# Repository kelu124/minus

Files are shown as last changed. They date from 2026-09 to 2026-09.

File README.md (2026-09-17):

# minus

**A minimal, single-channel, low-cost, open-source ultrasound pulse-echo platform —
built as a conference-workshop badge.**

`minus` drives one piezo transducer with a high-voltage pulse, amplifies and digitizes
the returning echo, and streams the raw data to a host. It is designed to be **cheap,
small, simple, and hackable** — a badge attendees can use in an ultrasound-conference
workshop (e.g. **muscle-contraction monitoring**, A-/M-mode) and then extend and
experiment with (coded excitation, on-device DSP, add-on boards).

> ⚠️ **Status: early design.** This repository currently holds the **requirements,
> a survey of comparable systems, a component trade study, and reference designs** —
> not yet a finished board. Non-clinical, for **research / education / NDT** only;
> not a medical device.

## What it is (at a glance)

- **MCU:** Raspberry Pi **RP2350** — precise pulse timing + fast ADC capture via PIO.
- **Signal:** **3–4 MHz** piezo (provided with the kit), **raw RF** A-mode + M-mode.
- **Front end:** unipolar HV pulser (bipolar option) → T/R switch → VGA/TGC → external
  high-speed ADC. Reuses proven blocks from the author's open boards.
- **Badge:** on-board **USB-C** (host + power), **RGB LED + small OLED** for standalone
  display, **Raspberry-Pi 40-pin** extension header, transducer via **SMA / header / uFL**,
  friendly silkscreen + test points, OSHWA certification planned.
- **Open:** open hardware + firmware + host software; designed for JLCPCB fabrication.

## Repository map

| Path | What's there |
|---|---|
| [`requirements.md`](requirements.md) | The design requirements (MoSCoW), with open decisions. |
| [`analysis.md`](analysis.md) | Architecture analysis — integrated vs external-ADC routes; pulser and gain options. |
| [`options.md`](options.md) + [`options_prices.csv`](options_prices.csv) | Component trade study (pulser / gain / ADC) with LCSC-referenced pricing. |
| [`systems/`](systems/README.md) | Survey of ~19 comparable ultrasound systems (datasheets, literature, by-IC index). |
| [`design/`](design/README.md) | Reference design files (un0rick, lit3rick, pic0rick, Open Echo, BioGAP shield). |
| [`pdfs/`](pdfs/README.md) | Source papers and component datasheets. |
| [`docs/claude/`](docs/claude/README.md) | Working notes: session logs, decision memory, TODO/DONE, changelog. |

## Lineage & credits

`minus` builds on the open single-channel ultrasound work of **Luc Jonveaux (kelu124)** —
[echomods/Murgen](https://github.com/kelu124/echomods),
[un0rick](https://github.com/kelu124/un0rick),
[lit3rick](https://github.com/kelu124/lit3rick), and
[pic0rick](https://github.com/kelu124/pic0rick) — reusing their proven building blocks
to reduce risk. See [`systems/`](systems/README.md) for the broader field survey.

## License

Intended to be released as **open hardware + open software** (OSHWA certification
planned), following the licensing of the boards above.

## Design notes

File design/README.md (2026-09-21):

# design — schematics & design files

Schematics, PCB / layout, Gerbers, BOMs, and other design source files for
reference designs (and, later, for *minus* itself). **One subfolder per design**,
named to match the system slug in [`../systems/`](../systems/) where one exists.

Convention:
- `design/<name>/` — e.g. `design/un0rick/`, `design/pic0rick/`, `design/iup/`.
- Put the raw design files here (KiCad, Gerbers, PDF schematics, BOM CSVs).
- Cross-link from the matching `systems/<name>/<name>.md` datasheet.
- Large binaries are fine, but prefer the canonical/original files; note the
  upstream source (repo URL + commit/version) in a short `SOURCE.md` per subfolder.

Datasheets and papers (not editable design files) go in
[`../pdfs/`](../pdfs/) instead.

## Collected so far

| Subfolder | Design | Contents |
|---|---|---|
| `un0rick/` | un0rick (iCE40 single-channel) | schematic PDF, BOM, gerbers, drills |
| `lit3rick/` | lit3rick (UP5K single-channel) | schematics PDF, BOM, gerbers, drills |
| `pic0rick/` | pic0rick (RP2040) — 3 boards | KiCad + schematic PDFs + gerbers for `adc/`, `mux/`, `panel_adc_pulser_hv/` |
| `biogap-wulpus-pro/` | BioGAP WULPUS-pro shield (MSP430FR5043) | schematics PDF, assembly PDF, BOM (Altium source upstream) |
| `open-echo/` | Open Echo TUSS4470 shield | KiCad sch/pcb/pro + gerbers + BOM |
| `pic32/` | **Concept** (no design files yet) | Thoughts on pairing a Microchip PIC32A (PIC32AK…GC41064: 40 Msps ADC + 100 MHz op-amps) with the RP2350 as an alternative acquisition architecture. |
| `designA/` | **Concept spec** (no design files yet) | Cheapest *minus* build: RP2354A + PIC32A, 5 V push-pull pulser, digipot-set gain; active-IC BOM ≈ $4.7 / board ≈ $6. |
| `devkit/` | **Concept spec** (no design files yet) | DesignA-DK: large, fully broken-out RP2354A + PIC32AK **derisking board** — one board, jumper-selected RX front-ends (FE-0…FE-D), gain-control options, pulser bench, SMA taps. |

Each has a `SOURCE.md` with the upstream repo URL + commit + retrieval date.
More to come (IUP if released, and the leads in `docs/claude/TODO.md`).

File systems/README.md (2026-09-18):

# systems — lightweight ultrasound acquisition survey

A survey of "lightweight" / low-cost single- and few-channel ultrasound
acquisition designs, used as background for **minus**. Sources: the
[wulrick extended platform survey](https://github.com/kelu124/wulrick#othersystems-extended-platform-survey)
and its `OtherSystems/` files, each system's primary papers/repos, and online
datasheets. **Scope:** single- to few-channel designs; **64+ element systems are
out of scope** (listed at the bottom for context only).

- **[`TEMPLATE.md`](TEMPLATE.md)** — the datasheet template. Copy into a new
  subfolder as `<slug>/<slug>.md` and fill it in. Covers MCU/FPGA, pulser
  (polarity/voltage), acquisition route, ADC, gain/TGC, connectivity bandwidth,
  wireless, channel scheme, performance, and power.
- **[`literature.md`](literature.md)** — broad literature review (≤32-element
  designs) distilled from the Jonveaux et al. 2022 open-hardware survey, plus
  component menus (pulsers, HV, TGC, ADC, AFE) and single-element B-mode strategies.
- **[`by-ic.md`](by-ic.md)** — designs grouped by key IC (MSP430FR5043, TUSS4470,
  AD833x, MD1213/TC6320, …) so a part choice traces to working references.
- **[`afe-vga-ics.md`](afe-vga-ics.md)** — survey of RX gain ICs (LNA + variable-gain /
  AFE), single-channel through 8/16-channel, for the *minus* gain stage.
- One subfolder per design/product. Source/confidence tags in each sheet:
  `[D]` datasheet/repo · `[P]` paper · `[S]` slides/survey · `[E]` estimate · `?` unknown.
- Source PDFs live in [`../pdfs/`](../pdfs/) (see its README).

## Systems at a glance

| System | Year | Arch | Channels | Pulser | ADC | Gain/TGC | Link | Power | Sheet |
|---|---|---|---|---|-----|---|---|---|---|
| **Murgen** (echOpen) | 2016 | MCU + modules | 1 | HV module | external | VGA (TGC) | USB | ? | [murgen](murgen/murgen.md) |
| **un0rick** | 2019 | FPGA (iCE40HX4K) | 1 | 25/50/75 V unipolar | 65 Msps ext. (10-bit) | TGC (AD8331+DAC) | SPI/USB/RPi | ~2 W | [un0rick](un0rick/un0rick.md) |
| **lit3rick** | 2021 | FPGA (iCE40 UP5K) | 1 | ext. HV module | ext. 12-bit | TGC (AD8332+DAC) | SPI/USB | ? | [lit3rick](lit3rick/lit3rick.md) |
| pic0rick | 2024 | MCU (RP2040) | 1 (+8 opt) | ±24 V bipolar | 65 Msps ext. (10-bit) | TGC (AD8331+DAC) | USB | ~300–400 mW | [pic0rick](pic0rick/pic0rick.md) |
| **IUP** (DRESDYN UDV node) | ~2025 | MCU+FPGA (STM32H7/iCE40) | 1 | ±32 V bipolar | 16 Msps ext. (16-bit) | TGC (AD8331+DAC) | Wi-Fi (ctrl) + SD | 2.96 W | [iup](iup/iup.md) |
| **MEMS-US** (single-el. scanner) | 2020 | single-el. + MEMS mirror + PC/DAQ | 1 | Olympus 5073PR | 100 Msps (12-bit) | SW TGC | PCIe | mains | [mems-us](mems-us/mems-us.md) |
| EchoLite | 2025 | MCU | 1 | ? | ? | ? | ? | 33 mW | [echolite](echolite/echolite.md) |
| PuLsE | 2025 | MCU (M4) | 1 | <15 V est. | integ., low-rate | none (analog envelope) | ? | **5.8 mW** | [pulse](pulse/pulse.md) |
| USoP | 2023 | MCU (flex) | 1 | ~10–30 V | integ. | ? | BT | 614 mW | [usop](usop/usop.md) |
| WULPUS | 2022 | MCU (MSP430) | 8 mux | +15 V unipolar | 8 Msps integ. (12-bit) | fixed PGA | BLE 320 kbps | 22 mW | [wulpus](wulpus/wulpus.md) |
| WULPUS PRO | 2026 | MCU (MSP430) | 16 mux | ±30 V | 8 Msps integ. (12-bit) | VGA + TGC (AD8338) | BLE/Wi-Fi | 35–58 mW | [wulpus-pro](wulpus-pro/wulpus-pro.md) |
| **BioGAP WULPUS-pro** | 2026 | MCU (MSP430) + BioGAP | 16 mux | 30 V | 8 Msps integ. | prog. VGA/TGC | BLE 1.4 Mb/s | ~tens mW | [biogap-wulpus-pro](biogap-wulpus-pro/biogap-wulpus-pro.md) |
| TinyProbe | 2025 | FPGA | 32 parallel | 64 Vpp (±32 V) | 30 Msps ext. (10-bit) | programmable TGC | Wi-Fi 21.6 Mb/s | <1 W | [tinyprobe](tinyprobe/tinyprobe.md) |
| TUSS4470 (IC route) | 2021 | AFE IC + MCU | 1 | bipolar H-bridge | external (envelope) | log-amp (not TGC) | SPI + VOUT | low | [tuss4470](tuss4470/tuss4470.md) |
| **Open Echo** (TUSS4470 board) | 2025 | TUSS4470 + Arduino/Pico | 1 | ~15–20 V boost | host ADC ~75 kSps/8-bit | log-amp | USB (PicoW: UDP) | USB | [open-echo](open-echo/open-echo.md) |
| **SENS-U** (commercial) | ~2019 | integrated (closed) | 4 mux→1 | ? | ? (integ.) | ? | BT | ? (36 h) | [sens-u](sens-u/sens-u.md) |
| **WMAUS** | ~2018 | MCU/DSP (dsPIC33) | 8 mux | ±15 V | 20 Msps ext. | VGA | BT/WiFi/Eth | 3.5 W | [wmaus](wmaus/wmaus.md) |
| **MoUsE** | ~2023 | FPGA (ZYNQ-7) | 32 parallel | ≤±100 V bf | 50 Msps ext. | TGC | raw 500 Mb/s | 12 W | [mouse](mouse/mouse.md) |
| **Flopatch** (commercial) | ~2023 | integrated (closed), CW | 2 (1TX+1RX) | CW 4 MHz | audio-rate | analog demod | BT | ? (180 min) | [flopatch](flopatch/flopatch.md) |

*`?` = not disclosed / to confirm. See each sheet for source tags and detail.
Broader ≤32-element literature (incl. Weik et al. 2026 Table I: Yin, Bashatah,
Wang, …) is tabulated in [`literature.md`](literature.md).*

### Piezo 1–5 MHz compatibility & sampling (quick reference)

Whether the front-end/ADC suits a **1–5 MHz piezo** (the *minus* target band), and
the ADC sampling speed. `Partial` = drives the band but bandwidth-limited.

| System | 1–5 MHz piezo? | Sampling |
|---|:---:|---|
| Murgen | Yes | external, build-dependent |
| un0rick | **Yes** | 65 MSps (10-bit) |
| lit3rick | **Yes** | ≤65 MSps (12-bit) |
| pic0rick | **Yes** | 65 MSps (10-bit) |
| IUP | Partial (≤~4 MHz) | 16 MSps (16-bit) |
| MEMS-US | Yes | 100 MSps (12-bit) |
| EchoLite | ? | ? |
| PuLsE | Yes | ~1–2 MSps (analog-envelope) |
| USoP | Yes (est.) | ? |
| WULPUS | Partial (1–3 MHz) | 8 MSps (12-bit) |
| WULPUS PRO | Partial (≤~3 MHz eff.) | 8 MSps (12-bit) |
| BioGAP WULPUS-pro | Partial (≤~3 MHz eff.) | 8 MSps |
| TinyProbe | **Yes** (≤15 MHz) | 30 MSps (10-bit) |
| TUSS4470 | **No** (≤1 MHz) | external (envelope, low-rate) |
| Open Echo | **No** (≤1 MHz) | ~75 kSps (8-bit) |
| SENS-U | ? | ? |
| WMAUS | Yes (5 MHz) | 20 MSps |
| MoUsE | Yes | 50 MSps |
| Flopatch | Yes (4 MHz, CW) | audio-rate (kHz) |

**For minus (1–5 MHz target):** the external-ADC route (un0rick/lit3rick/pic0rick,
30–65 MSps) covers 1–5 MHz cleanly; the MSP430 integrated route (WULPUS family,
8 MSps) is bandwidth-capped to ≤~3 MHz; the TUSS4470/Open-Echo route (≤1 MHz) is out
of band. See [`../analysis.md`](../analysis.md).

## Reading the design space

Five architectural branches, ordered roughly minimal → capable:

1. **Integrated analog-envelope front-end IC** — TUSS4470. Fewest parts, lowest
   power, but ≤1 MHz and envelope-only (no RF phase). The floor of the design space.
2. **Analog-envelope + low-rate ADC** — PuLsE (5.8 mW). Custom envelope circuit ⇒
   slow ADC + low-power MCU. Envelope-only; wearable HR.
3. **Integrated-ADC MCU** — WULPUS / WULPUS PRO. 8 Msps integrated ADC caps
   end-to-end BW at ~1.4 MHz (≤3 MHz transducers). PRO adds analog TGC (AD8338) and
   a dual ±30 V supply (LT3463). Lowest power for raw-RF A-mode.
4. **External high-speed-ADC, single channel** — Murgen → un0rick → lit3rick →
   pic0rick (the kelu124 family). 65 Msps (10–12-bit) external ADC + AD833x VGA/TGC
   + MD-class pulser. High frequency, USB/SPI, higher power. **The direct lineage
   for *minus*.**
5. **FPGA multi-channel** — TinyProbe (32 ch, Wi-Fi). High capability, ~45× the
   power. Upper bound of the "few-channel" space before going out of scope.

Plus an orthogonal axis — **integration-first**: USoP (flexible skin patch, power
spent on conformability, 614 mW).

**For minus** (minimal, single-channel, cheap), the most directly relevant are the
**kelu124 family** (un0rick / lit3rick / pic0rick — the baseline to trim), **WULPUS**
(minimal-power raw-RF A-mode), **PuLsE / TUSS4470** (how far envelope-only
minimalism can go). The core tension: external high-speed ADC (frequency + cost +
power) vs integrated slow ADC (cheap + low-power, but ≤~1.4 MHz).

## Out of scope — 64+ element / large systems (context only)

Not given datasheets (per the "avoid 64+ elements" guidance); recorded so we know
they were reviewed and set aside:

- **ULA-OP / ULA-OP 256** (Univ. Florence) — open research platform; base 64-ch,
  scalable to 256 (Artix-7 FPGA per 32-ch module). Powerful but large/expensive.
- **SARUS** (DTU, Denmark) — up to 1024 ch (64 boards × 16), 320 FPGAs + Linux
  cluster. Research beamforming reference; far out of scope.
- **open-UST** (arXiv 2302.10114) — open-source ultrasound *tomography* transducer
  array; many-element ring. Different modality; out of scope.

## Leads to review (not yet sheeted)

- **Compact modular open platform for low-cost ultrasound imaging**, *Measurement*
  2024 (ScienceDirect S0263224124022516) — **32 elements (in scope, confirmed).**
  To sheet: get the PDF into `pdfs/` and fill a datasheet.
- **rtl-ultrasound** (Meng 2019) — SDR-based quadrature acquisition path (a review
  co-author's project). In scope; sheet it.
- **Compressive single-sensor 3D** (Kruizinga et al. 2017) — single-element
  volumetric imaging via a coded aperture mask. In scope; sheet it.
- Historical context only: "Design of low-cost portable ultrasound systems: review"
  (PubMed 19963733).

*Dropped:* AFE58xx AI-portable US (arXiv 2311.00482) — 64+ channels, out of scope.
**Sheeted since:** MEMS-US (Sci. Reports 2020) now has its own datasheet.

## Literature & source PDFs

- **Anchor surveys:**
  - Jonveaux, Schloh, Meng, Arija, Rintoul, *Journal of Open Hardware* 6(1):3, 2022,
    DOI 10.5334/joh.28 (`pdfs/28-952-1-PB.pdf`) — components/architecture.
  - Weik et al., *Current Trends in Ultrasound Wearables: Spotlight on System
    Architecture*, IEEE Reviews in Biomedical Engineering, 2026 (early access)
    (`pdfs/Current_Trends_..._early_access.pdf`) — wearable system-architecture +
    Table I comparison. Peer-reviewed basis of the **SIG-WUS OXP** catalog
    (<https://sig-wus.org>, GitHub `sig-wus`; live catalog data didn't load — revisit).
  - Both distilled in [`literature.md`](literature.md).
- **SIG-WUS OXP catalog snapshot:** [`_sig-wus-oxp/`](_sig-wus-oxp/README.md) — the
  live web catalog's underlying JSON (14 platforms), pulled from the `sig-wus` repo,
  with a catalog-vs-datasheet reconciliation table.
- Device papers: IUP (`pdfs/ssrn-6946751.pdf`), MEMS-US (`pdfs/s41598-020-63529-z.pdf`);
  pic0rick article (`pdfs/pic0rick_full.pdf`).
- New PDFs (datasheets, reference designs) go in [`../pdfs/`](../pdfs/); any
  schematics / design files go in [`../design/<name>/`](../design/) (one subfolder
  per design, each with a `SOURCE.md`). Collected so far: un0rick, lit3rick, pic0rick.

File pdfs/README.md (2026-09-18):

# pdfs — source documents

Papers, datasheets, and reference-design documents backing the survey and the
*minus* design work. Store any PDF you download here (rather than a temp dir), with
a descriptive name.

**Markdown siblings:** every PDF here keeps a `.md` version of the same basename
sitting next to it (e.g. `foo.pdf` → `foo.md`), so the text is greppable and cheap to
read without re-parsing the PDF. Generate it with the locally-installed **markitdown**:
`markitdown foo.pdf -o foo.md`. Commit the `.md` with the PDF.

| File | What it is |
|---|---|
| `28-952-1-PB.pdf` | Jonveaux, Schloh, Meng, Arija, Rintoul — *Review of Current Simple Ultrasound Hardware Considerations, Designs, and Processing Opportunities*, Journal of Open Hardware 6(1):3, 2022 (DOI 10.5334/joh.28). Anchor survey → `systems/literature.md`. |
| `ssrn-6946751.pdf` | HZDR — *Integrated Ultrasound Platform (IUP)*, distributed UDV sensor node for DRESDYN (SSRN preprint). → `systems/iup/`. |
| `s41598-020-63529-z.pdf` | Choi et al. — *Versatile Single-Element Ultrasound Imaging Platform using a Water-Proofed MEMS Scanner*, Scientific Reports 10:6544, 2020. → `systems/mems-us/`. |
| `rp2350-datasheet.pdf` | Raspberry Pi RP2350 datasheet (RP2350A/B; on-chip 12-bit SAR ADC = 500 kSps). Context for MCU/ADC choice. |
| `pic0rick_full.pdf` | pic0rick article (full version), from the kelu124/pic0rick repo. → `systems/pic0rick/`; design files in `design/pic0rick/`. |
| `Current_Trends_in_Ultrasound_Wearables_Spotlight_on_System_Architecture_early_access.pdf` | Weik et al., *Current Trends in Ultrasound Wearables: Spotlight on System Architecture*, IEEE Reviews in Biomedical Engineering (early access, 2026). Peer-reviewed basis of the SIG-WUS catalog. |

Component **datasheets** live in [`datasheets/`](datasheets/README.md) (pulser ICs
etc. — see `analysis.md`).

Related: schematics and design files (KiCad/Gerber/PDF schematics) go in
[`../design/<name>/`](../design/), one subfolder per design.

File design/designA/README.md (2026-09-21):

# DesignA — cheapest RP2354A + PIC32A single-channel pulse-echo badge

**Status:** concept spec (2026-09-18). No schematic yet — this is the architecture +
BOM + pulser/gain detail for the **cheapest** *minus* build. Derives from the concept
in [`../pic32/`](../pic32/README.md); obeys `requirements.md` (DP1–DP3 small/cheap/
simple, F6 per-line settable gain / no TGC, T1–T4 unipolar coded pulser).

> **Prior art / reuse (DP5):** the PIC32A analog front-end here follows the owner's own
> **[kelu124/pic32arick](https://github.com/kelu124/pic32arick)** (a PIC32AK1216GC41064
> board: 5 V pulser + op-amp chain + ADC, no RP). DesignA = **pic32arick's proven PIC32
> front-end + an RP2354A** for USB-C/manager/DSP + one-cable programming. The pulser,
> gain chain, T/R and ICSP-header choices below adopt pic32arick's validated blocks.

> **⚠ Open design issues:** a multi-agent review (2026-09-21) found flaws to resolve before
> fab — see [`../devkit/review-findings.md`](../devkit/review-findings.md). Factual
> datasheet corrections (VREF=AVDD, op-amp High/Low-power specs, ENOB ~10.5-bit, TC4427A
> has no internal dead-time / is 8-pin) are applied below; deeper items (gain-stage
> bandwidth, anti-alias corner, USB-C Rd, MCLR isolation) are flagged inline.

## 1. Idea in one line

**RP2354A** (USB-C host + manager + DSP, *2 MB in-package flash → no external flash*)
paired with a **PIC32A** (on-die 40 Msps ADC + three 100 MHz op-amps = the whole analog
gain+capture chain) — two small QFNs, a 5 V push-pull pulser (pic32arick-proven), and a
digipot-set per-line gain. Target **active-IC BOM ≈ $4.7**, whole board ≈ **$6**
(ex-piezo); an absolute-minimum single-N-FET variant ≈ $5.4.

## 2. Block diagram

```mermaid
flowchart LR
  USB["USB-C 5V"] --> LDO["3V3 LDO"]
  USB --> HV["+5V pulser rail<br/>(T7 jumper)"]

  subgraph RP["RP2354A · QFN-60"]
    RPfn["USB-C host · manager · DSP<br/>2MB in-package flash · WS2812"]
  end
  subgraph PICc["PIC32A · 48-pin"]
    TXP["HS-PWM (TX)"]
    GAIN["op-amp + digipot gain"]
    ADCc["12-bit 40 Msps ADC"]
    GAIN --> ADCc
  end

  LDO --> RP
  LDO --> PICc
  RPfn <-->|"SPI + RDY + TRIG"| PICc
  RPfn -->|"ICSP MCLR/PGC/PGD"| PICc
  ADCc -->|"A-line over SPI"| RPfn

  PZ["piezo ~3-4 MHz<br/>(provided)"] --> TR["T/R switch<br/>MD0100"] --> GAIN
  TXP --> JP1{{"JP1 drive-select"}}
  RPfn -.->|"PIO (alt)"| JP1
  JP1 --> GD["TC4427A driver"] --> Q1["push-pull FETs<br/>IRLML6244/2244"]
  HV --> Q1
  Q1 --> PZ
```

Roles: **PIC32A owns TX + capture** (HS-PWM fires the pulser and triggers its own ADC
on-chip → no cross-chip timing); **RP2354A owns USB, control, DSP, display, and flashes
the PIC over ICSP** (one USB-C port programs both). Interconnect detail:
[`../pic32/` §3d](../pic32/README.md).

## 3. BOM (cheapest, qty ~50)

| # | Part | Role | ~$ | Source |
|---|---|---|----|---|
| U1 | **RP2354A** (QFN-60) | MCU / USB-C / mgr / DSP; **2 MB internal flash** | **1.27** | **LCSC C41378174 / JLC ✓** (16k stk) |
| U2 | **PIC32AK3208GC41048** (48-pin) | capture engine: 40 Msps 12-bit ADC + 100 MHz op-amps | **~1.73** | Digikey ✓; **not LCSC** → consigned (N2) |
| Q1,Q2 | IRLML6244 (N) + IRLML2244 (P) | push-pull unipolar pulser (both edges driven) | 0.20 | LCSC ✓ |
| U5 | TC4427A dual gate driver (**8-pin**) | 3V3→5V gate drive (**no internal dead-time** — must come from the PWM source, or use a tied-gate CMOS totem; see review-findings A5/A6) | 0.30 | LCSC ✓ |
| D1 | MD0100 (T/R switch) | protect RX from TX edge (BAV99 = cheaper fallback) | ~0.60 | Digikey (BAV99 LCSC) |
| U3 | digital pot MCP4531-103 (I²C) | per-line settable gain (OA2 gain resistor) | ~0.40 | LCSC ✓ |
| U4 | 3V3 LDO (ME6211 / AP2112) | 3V3 from USB 5V | 0.10 | LCSC ✓ |
| D2 | WS2812B / SK6812 | autonomous RGB status (PIO) | 0.10 | LCSC ✓ |
| Y1 | 12 MHz crystal | RP2354 USB clock | 0.10 | LCSC ✓ |
| J1 | USB-C receptacle | host + power | 0.30 | LCSC ✓ |
| J2 | 2×1 2.54 header + uFL | transducer (F2c) | 0.30 | LCSC ✓ |
| JP1 | 3-pin header + shunt | **pulser drive-select** (PIC32 HS-PWM ⟷ RP2354 PIO, req T4a) | 0.05 | LCSC ✓ |
| J3 | 6-pin ICSP / Tag-Connect pads | **PIC32 ICSP** — flash w/ PICkit (req S4a, see pic32.md) | 0.10 | LCSC ✓ / zero-BOM |
| — | ferrite bead + passives (R/C, decoupling) | — | ~0.55 | LCSC ✓ |
| **Active ICs** | U1+U2+Q1,Q2+U5+D1+U3+U4+D2 | | **≈ $4.70** | |
| **Board total** | + Y1/J1/J2/JP1/J3/passives | (ex-piezo, provided) | **≈ $6.3** | |

**Absolute-minimum variant** (~$0.9 less): single N-FET (2N7002) instead of push-pull +
TC4427A, and BAV99 instead of MD0100 → board ≈ **$5.4**, at the cost of softer edges /
longer ring-down.

**Optional (not in cheapest):** SSD1306 I²C OLED (~$1.2, F12), RP2 40-pin header
(C5, ~$0.2, can be unpopulated pads), a fixed LNA (LMH6629/ADA4898-1, ~$5, only if SNR
limits — A3a).

> **Cost vs baseline:** the RP2350+external-ADC+VGA "cheapest realistic" build is ~$33
> (options.md). DesignA is **~$6** because the ADC **and** the whole op-amp gain chain
> fold into the $1.7 PIC32A and the flash folds into the RP2354A. **Only caveat:** the
> PIC32A is not LCSC-stocked (consigned/Digikey), the one N2 hit — everything else is
> LCSC/JLC.

## 4. Pulser stage (unipolar, 5 V, = options.md U0)

**Recommended (pic32arick-proven): push-pull complementary MOSFETs through a dual gate
driver.** Both edges are actively driven → transducer ring-down ~1–2 µs (vs RC decay),
i.e. a smaller dead zone. This is the owner's validated 5 V pulser.

```
        +5V pulser rail (USB VBUS via ferrite bead; T7 jumper for external HV)
          │
        [P-FET IRLML2244] ── pulls HIGH
          ├───────────────┬─────────────► piezo hot node ──► [MD0100 T/R] ──► RX gain
        [N-FET IRLML6244] ─┘ pulls LOW    │
          │                            [Rdamp 100–200Ω to GND]  ← ring-down damping
         GND
        gates ◄── [TC4427A dual gate driver (8-pin), 3V3→5V level-shift — dead-time from PWM]
                         ▲
   ┌───────── JP1 (drive-select) ─────────┐
  PIC32A HS-PWM ●  ○── shunt ──○  ● RP2354 PIO
  (complementary PWM pair)        (PIO complementary pair)
```

- **Push-pull (recommended):** **N-FET IRLML6244** + **P-FET IRLML2244** (SOT-23, 20 V —
  keep the totem rail ≤ ~15 V; boost/HV belongs to the MD1213 path, review-findings B7),
  driven by a **TC4427A** dual gate driver (**8-pin**, 1.5 A, level-shifts 3.3 V logic to
  the 5 V gate). **The TC4427A has NO internal dead-time** — for a complementary pair the
  PWM source must insert dead-time, **or drive the totem as a tied-gate CMOS pair (one
  signal, no dead-time — recommended)**. Realistic edges at 5 V are **~20–30 ns** (not the
  earlier "4–5 ns"); peak gate current ~400–600 mA into a ~500 pF piezo. 5 V trades
  ~20–26 dB SNR vs a 100 V MD1213 pulser (< 5 cm penetration) but is cheap and HV-safe.
  **Active damping** option: fire a second, opposite pulse ~T/2 later. *(Topology decision
  + faster-driver option: review-findings B7/C1/C2.)*
- **Absolute-minimum variant:** a **single low-side N-FET** (2N7002/AO3400) straight
  off 5 V with a **BAV99** clamp instead of the MD0100 — ~$0.5 cheaper, but softer edges
  / longer ring-down. Use only if shaving the last cents matters.
- **T/R protection (A2):** **MD0100** shunt-diode T/R switch (pic32arick) isolates the
  TX edge from the PIC op-amp input; BAV99-to-rails is the cheaper fallback.
- **Drive — jumper-selectable (req T4a):** the gate-driver **input** is fed by **either**
  the **PIC32A HS-PWM** (complementary pair, 2.5 ns res — tight on-chip TX↔ADC sync) **or**
  the **RP2354 PIO**, chosen by **JP1**. **Only one drives at a time** (the other Hi-Z).
  Both do multi-cycle bursts, chirp, pulse-train and OOK **coded excitation** (T4). The
  TC4427A sits **after** JP1, serving whichever source is selected.
- **Rail:** 5 V pulser supply isolated from logic by a **ferrite bead (~600 Ω @ 100 MHz)**
  + local decoupling; **HV node on the T7 jumper** so external HV can replace it later.
- **Amplitude:** ~5 V — enough for a **shallow (1–4 cm) muscle demo**; lean on the gain
  stage + averaging + coded excitation.

## 5. Gain stage (no TGC — per-line settable)

Per `requirements.md` F6/A3: **no TGC**; the user sets a **fixed gain, re-settable
between firing lines.** Adopts the **pic32arick 3-op-amp chain** — all three op-amps are
**on-die in the PIC32A** (zero extra amplifier ICs); only the digipot is external:

```
 RX ─[MD0100]─► OA1 fixed  ──► OA2 variable ──► [2-pole RC AAF] ──► PIC32A ADC (12b/40Msps)
                +14.5 dB        6–42 dB            (100Ω+56pF)×2       (internal route)
                (Rf1 4.3k/       gain set by
                 Rg1 1k)         MCP4531-103 digipot (I²C)
                                       ▲
       OA3 = mid-rail bias buffer      └── wiper code set per line by RP2354/PIC (I²C)
```

- **OA1 — fixed first stage** (non-inverting, 1+4.3k/1k ≈ **5.3× / +14.5 dB**, Cf 2.2 pF):
  gain kept constant so the **noise figure** is set once (best sensitivity).
- **OA2 — variable stage:** non-inverting, gain resistor = **MCP4531-103** digital pot
  (I²C, 10 kΩ/128 steps) → **~2–129× (6–42 dB)**; Rf2 10 k, Cf2 1.5 pF. Firmware writes
  the wiper code **once per line** (no TGC).
- **OA3 — mid-rail bias** unity-gain buffer (single-supply biasing).
- **Combined:** ~**+20.5 dB … +56.5 dB** *on paper* — but **finite op-amp GBW (100 MHz
  High-Power / 50 MHz Low-Power) caps usable gain at 3–4 MHz to ≈ +34 dB**; the top of the
  range needs an LNA or a real VGA (review-findings **B1**). Then a **2-pole RC anti-alias**
  — the drawn (100 Ω+56 pF)×2 (~28 MHz corner) is **too high for a 40/20 Msps ADC; move to
  ~6–8 MHz** (review-findings **B3**) — into a **PIC32A 12-bit 40 Msps ADC** (on-die).
- **Why a digipot, not a DAC:** gain lives in the **resistor ratio**; the digipot *is*
  the gain resistor. Firmware writes the code once per line (static within a line). A DAC
  *voltage* only sets gain in a true VGA/multiplier.
- **Capture:** ≤ ~150 µs @ 20 Msps (6 KB of the PIC's 8 KB SRAM); PIC bursts the A-line
  to RP2354 over SPI.
- **Cheaper alternative:** a resistor bank + analog mux (74HC4052) gives 3–4 discrete
  gain steps instead of the digipot — if a few levels suffice.
- **Optional LNA (A3a):** the PIC op-amps are general-purpose; if weak-echo SNR limits
  the demo, add a fixed low-noise LNA first stage (LMH6629/ADA4898-1/OPA847 ~$5). Omitted
  in the cheapest build.

### 5a. ADC input conditioning (single-supply — critical)

The PIC32A runs on **one 3.0–3.6 V rail**, so its op-amps and ADC **cannot see < 0 V**.
Ultrasound RF is 0-centered (≈ ±2 V raw), so it must be **biased to mid-rail and scaled**
to fit; never fed in bipolar.

- **ADC range (single-ended, reference = AVDD ≈ 3.3 V): 0 → VREF**, 12-bit (**ENOB ≈
  10.5 bits**) → **LSB ≈ 0.8 mV**. **No external VREF+ pin on this family** — reference is
  AVDD (corrected 2026-09-21). Use **single-ended**: the "~±VREF/4" differential limit is
  from generic dsPIC33A docs, **not the PIC32AK datasheet — verify**; single-ended is the
  safe larger window. Pins must stay 0–3.3 V (ESD clamps conduct beyond → damage + long
  recovery).
- **Bias to VREF/2 ≈ 1.65 V** (code ≈ 2048): **OA3** supplies this mid-rail reference to
  the gain-stage inputs so the output centres at 1.65 V and swings ±.
- **AC-couple** the front-end into the op-amp (series cap + mid-rail bias); set the
  high-pass corner **< ~100 kHz** so 3–4 MHz passes flat and DC/pulser offset is blocked.
- **Fit the swing with headroom:** target **~2.6–2.8 Vpp** (≈ ±1.3–1.5 V around 1.65 V),
  staying ~0.2–0.3 V off each rail (op-amp output limit + ADC non-linearity near rails).
  ⇒ a raw **±2 V (4 Vpp) is too big** — set the gain so the **largest echo of interest
  ≈ ±1.4 V**, not the transducer's raw peak.
- **Clamp for overrange:** MD0100 T/R + a diode limiter to the rails at the ADC/op-amp
  node keeps TX leakage / strong near-field spikes inside 0–3.3 V.
- **Auto-range:** the per-line digipot gain doubles as the fit-to-ADC control — fire →
  read peak code → back off a step if near full-scale → refire (RP2354/host loop).

### 5b. Acquisition tightly coupled to TX (hardware trigger)

Because the **PIC HS-PWM that drives the pulser can also emit the ADC trigger** off the
**same counter**, acquisition is phase-locked to the first pulse edge with **~2.5 ns
resolution and zero firmware jitter**:

- **PWM-generated ADC trigger (default):** set the PWM generator's trigger-compare to the
  count of the first pulser edge (t = 0), or add a programmable delay to blank the TX
  artifact / set a near-field start. Same counter ⇒ cycle-accurate.
- **PTG** (Peripheral Trigger Generator) sequences *fire burst → wait → trigger ADC* for
  coded-excitation bursts; **ADC window mode** can gate the acquisition from PWM/PTG.
- **Requires PIC-owns-TX** (JP1 → PIC HS-PWM) for the tightest coupling — TX + ADC share
  the PIC's timebase. If RP2354 owns TX, route its pulse-start into the **PIC ADC external
  trigger (TRIG)** — still hardware, but crosses a chip boundary (added delay/jitter). So
  **PIC-HS-PWM-owns-TX is the recommended JP1 default** for coupled acquisition.

## 6. Power & clocks

- **USB 5 V** in (J1) → pulser rail (5 V) + **3V3 LDO** (U4) for both MCUs, digipot, LED.
- RP2354 **QSPI_IOVDD must be 3.3 V** (internal flash); PIC32A runs 3.0–3.6 V — one 3V3
  rail suits both.
- RP2354 USB needs a **12 MHz crystal** (Y1); PIC32A runs off its internal FRC+PLL (no
  crystal).
- **BOOTSEL:** button from RP2354 **QSPI_CSn (SS) → GND via ~1 kΩ**, pressed at power-up
  (same as flashless RP2350A); optional **RUN reset** button to enter BOOTSEL without a
  power cycle.

## 6b. Programming / flashing (two paths)

Both MCUs must be flashable; DesignA gives **two independent routes** (req S4 / S4a):

- **RP2354A** — native **USB-C BOOTSEL → UF2** drag-and-drop (no tools). It can also act
  as the PIC programmer over the ICSP lines (§3d).
- **PIC32A** — flashed **directly over ICSP** via a **5-pin header J3** (standard
  Microchip order: **MCLR/Vpp, VDD, VSS, PGD(ICSPDAT), PGC(ICSPCLK)**) with a **PICkit
  4/5 or MPLAB Snap** — a provided `.hex` flashes with free **MPLAB IPE** (no compiler
  needed). Route **one PGECx/PGEDx pair + MCLR** to J3; keep the standard MCLR network
  (10 kΩ pull-up to VDD, no cap loading Vpp). The **same PGC/PGD/MCLR net is shared** with
  the RP2354-over-ICSP path — so either a PICkit *or* the RP2354 can program the PIC.
  Full detail: [`../pic32/pic32.md`](../pic32/pic32.md).

```mermaid
flowchart TD
  PC["Dev PC<br/>MPLAB IPE / X"] -->|USB| PK["PICkit 4/5 or Snap"]
  PK -->|"ICSP · J3 (5-pin)"| PIC["PIC32A"]
  UF2["USB-C · BOOTSEL → UF2"] --> RP["RP2354A"]
  RP -.->|"bit-bang LVP ICSP<br/>(shared PGC/PGD/MCLR)"| PIC
  N["One programmer at a time;<br/>idle side's ICSP pins Hi-Z"]:::note
  classDef note fill:#eeeeee,stroke:#999999,stroke-dasharray:3 3;
```

## Acquisition sequence (one A-line)

```mermaid
sequenceDiagram
  participant H as Host (USB)
  participant R as RP2354A
  participant P as PIC32A
  participant T as Piezo
  H->>R: configure (freq, cycles, PRF, gain, depth)
  R->>P: params + gain code (SPI)
  R->>P: TRIG (start)
  P->>T: HS-PWM burst via N-FET (coded excitation)
  T-->>P: echo → T/R clamp → op-amp+digipot → ADC
  Note over P: capture ≤150µs @20Msps into 8KB SRAM
  P-->>R: RDY (line ready)
  R->>P: read A-line (SPI burst)
  R->>R: optional DSP (bandpass/envelope/matched filter)
  R-->>H: raw/processed A-line ; RGB/OLED update
```

## 7. Open risks / to verify

- [ ] **PIC32A sourcing (N2):** not LCSC/JLC-stocked → consigned part or Digikey +
      hand-place. The one non-JLC part in DesignA. (RP2354A **is** on JLC — C41378174.)
- [ ] **PIC32A op-amp noise** vs echo level → is the optional LNA (A3a) actually needed?
- [ ] **Digipot bandwidth/parasitics** on OA2 (MCP4531 wiper capacitance) at 3–4 MHz —
      validate, or fall back to the resistor-mux.
- [ ] **MD0100 vs BAV99** T/R (BAV99 clamps to ~4.3 V > PIC abs-max — needs series R,
      5 V-only; review-findings C4). **Dead-time / shoot-through:** TC4427A has none — use
      tied-gate totem or PWM-inserted dead-time (C1). Add a **10 kΩ pull-down on the
      driver input** (JP1 off = pulser off, C3).
- [ ] Confirm PIC32A **48-pin** pin budget with this exact signal set (§3c/§3d) — now
      incl. JP1 drive-select (2 pins) + J3 ICSP.
- [ ] **JP1 drive-select (T4a):** firmware must set the *unselected* MCU's gate pin to
      Hi-Z/input; verify no contention and that both a PIC32 HS-PWM pin and an RP2354 PIO
      pin reach JP1.
- [ ] **Shared ICSP net:** PICkit-vs-RP2354 contention on PGC/PGD/MCLR (§6b, pic32.md) —
      RP2354 pins Hi-Z when a PICkit drives J3.
- [ ] RP2354A qty-50 LCSC price (base ~$1.27) and PIC32A qty-50 Digikey price.

## 8. Links
- **Prior art (owner's PIC32A board):** [kelu124/pic32arick](https://github.com/kelu124/pic32arick)
  — pulser, op-amp chain, programming header this design reuses.
- **Toolchain (Ubuntu CLI + Makefile):** [`toolchain_designA.md`](toolchain_designA.md).
- **PIC32 flashing / ICSP header:** [`../pic32/pic32.md`](../pic32/pic32.md).
- Concept + trade study: [`../pic32/README.md`](../pic32/README.md) (§3a BOM, §3b gain,
  §3c chip/footprint, §3d interconnect).
- Gain/LNA IC survey + prices: [`../../systems/afe-vga-ics.md`](../../systems/afe-vga-ics.md).
- Component trade study: [`../../options.md`](../../options.md); requirements:
  [`../../requirements.md`](../../requirements.md).

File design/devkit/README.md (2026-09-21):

# DesignA-DK — RP2354A + PIC32AK development kit (derisking board)

**Status:** concept spec (2026-09-21). The **eval/derisk** sibling of
[DesignA](../designA/README.md): same silicon (RP2354A + PIC32AK), but **large, fully
broken-out, and modular** so every contested front-end / pulser / gain decision can be
**swapped and measured** on the bench before the cheap DesignA badge is frozen.

> **⚠ Review findings:** a 4-agent flaw review (2026-09-21) is captured in
> [`review-findings.md`](review-findings.md) — read it before committing the schematic.
> Confirmed datasheet corrections are applied throughout; higher-severity design flaws
> (B/C) are tracked there.

## 1. Philosophy — measure, don't guess

Space and BOM are *not* constraints here. So every design choice that is currently an
open question becomes either an **on-board block behind a jumper**, a **populate-option**,
or a **routing jumper** — one board, no daughter-cards — and every analog node gets a
**test point / SMA tap**. The devkit's job is to
turn the open items in [`../designA`](../designA/README.md) §7 and
[`../pic32`](../pic32/README.md) §5 into **bench measurements**.

## 2. What we're derisking (map)

| Open decision | How the devkit answers it |
|---|---|
| PIC32A ADC real perf (ENOB, gap-free 40/20 Msps, SRAM depth) | SMA inject a known tone/pulse at the ADC node; capture; measure. Also derisk on vendor eval HW (§9). |
| Do we need an external **LNA**, or are the PIC op-amps enough? | Jumper-select FE-0…FE-D (§4); compare SNR on the same target. |
| **ADC input conditioning** (mid-rail bias, ~2.8 Vpp fit, clip onset, ENOB near rails, AC-coupling corner) | Bias-point test point; SMA inject a known ±V swing; sweep gain to clip; measure ENOB vs level (DesignA §5a). |
| **TX↔ADC hardware trigger** (PWM-generated trigger jitter/delay) | Scope TX first edge vs ADC-start on a test point; measure jitter/pre-delay; compare PIC-HS-PWM vs RP2354-via-TRIG (DesignA §5b). |
| **Gain-control** method (digipot I²C vs SPI vs resistor-mux vs VGA Vgain) | Populate-options + a common gain bus (§5); compare BW/steps/noise. |
| **Pulser**: push-pull vs single-FET; 5 V enough?; ring-down | Pulser bench with both fitted + HV-rail select + damping options (§6). |
| **TX drive source** (PIC HS-PWM vs RP2354 PIO) | JP1 drive-select (as DesignA) — try both. |
| **T/R**: MD0100 vs BAV99 vs none | Populate-option on each FE card / mainboard. |
| Inter-MCU **SPI/RDY/TRIG** + **ICSP-from-RP2354** | All lines on headers + test points; both programming paths. |
| **Pin budget** | Use the 64-pin PIC (no budget worries); down-spec later. |

## 3. Core spine (fixed)

- **RP2354A** (QFN-60) — USB-C, manager, DSP, WS2812, ICSP programmer. 2 MB internal flash.
- **PIC32AK6416GC41064** (64-pin) — **64 KB flash / 16 KB RAM** (enough for 150 µs @ full
  40 Msps) and **max pins/analog inputs** so nothing is pin-limited during eval. (DesignA
  down-specs to the 48-pin `3208` once decisions lock.)
- **USB-C** (host+power) + optional **barrel/bench-supply** input via jumper.
- **Power: split, jumpered rails** — separate **AVDD (analog 3V3)** and **DVDD (digital
  3V3)** each behind a 0 Ω / ferrite + a current-sense pad, so analog noise contributions
  are measurable. Pulser 5 V rail isolated by a ferrite (as pic32arick).
- **Programming:** both paths — a **6-pin ICSP header (+ Tag-Connect pads)** for a PICkit,
  *and* the RP2354-over-ICSP net. RP2354 BOOTSEL + RUN buttons.
- **Everything broken out:** all PIC32 GPIO/analog/op-amp/HS-PWM pins and RP2354
  GPIO/PIO to **labelled 0.1″ headers** (classic dev-board fan-out).

## 4. On-board RX front-ends, jumper-selected (the key derisk)

**No mezzanine / daughter-cards.** All front-end blocks live on the **one board**,
populated in parallel; a pair of jumpers routes exactly **one path** at a time from a
common **RX node** (after the T/R) to a common **ADC node** (the PIC32 ADC input).

**Routing scheme** — each block taps the RX node through its own **input jumper**
(`JIN_*`) and drives the ADC node through its own **output jumper** (`JOUT_*`). Fit one
`JIN`+`JOUT` shunt pair to select a path; the unused blocks are left un-jumpered (isolated,
no loading). FE-0 is a single RX→ADC link.

```mermaid
flowchart LR
  PZ["transducer / SMA inject"] --> TR["T/R (populate:<br/>MD0100 / BAV99)"]
  TR --> RXN(["RX node"])
  RXN -->|JIN_0| ADCN
  RXN -->|JIN_A| OA["PIC op-amps<br/>OA1 fixed / OA2 digipot"]
  RXN -->|JIN_B| LNA["ext LNA<br/>AD8432/LMH6629"]
  RXN -->|JIN_C| V1["AD8331 LNA+VGA"]
  RXN -->|JIN_D| V2["AD8338 VGA"]
  LNA -->|JIN_B2| OA
  OA -->|JOUT_A| ADCN
  V1 -->|JOUT_C| ADCN
  V2 -->|JOUT_D| ADCN
  LNA -->|JOUT_B| ADCN
  ADCN(["ADC node"]) --> ADC["PIC32 ADC<br/>12-bit 40 Msps"]
  ADC -->|"SPI + RDY"| RP["RP2354A<br/>USB-C · DSP · programmer"]
  RP -->|"TRIG / JP1"| PLS["pulser (push-pull / single-FET)"]
  RP -->|ICSP| ADC
  PLS --> PZ
  GAIN["gain bus (§5): I²C · SPI · VGAIN"]:::note
  classDef note fill:#eeeeee,stroke:#999999,stroke-dasharray:3 3;
```

Selectable paths (all on the one board; pick with the `JIN`/`JOUT` shunts):

| Path | JIN / JOUT | Route | Tests |
|---|---|---|---|
| **FE-0 straight** | JIN_0 | RX → ADC (no gain) | baseline noise floor / dynamic range |
| **FE-A PIC-opamp** | JIN_A / JOUT_A | RX → PIC OA1(fixed) → OA2(digipot) → ADC | the DesignA path |
| **FE-B LNA + PIC-opamp** | JIN_B / JIN_B2 / JOUT_A | RX → **LNA** → PIC OA → ADC | does an LNA lift SNR? |
| **FE-C ext VGA** | JIN_C / JOUT_C | RX → **AD8331** → ADC (bypass PIC opamps) | proven ultrasound VGA reference |
| **FE-D ext VGA LP** | JIN_D / JOUT_D | RX → **AD8338** → ADC | low-power/cheaper VGA |

> This is "different front ends on top of the PIC32 op-amps" without connectors: FE-B feeds
> the PIC op-amps through an external LNA; FE-C/D bypass them; FE-0 skips gain — each is a
> jumper choice, measured against FE-A on the same target. Keep the parallel input taps
> **short** and place `JIN` links right at the RX node to minimise stubs on the RF path.

## 5. Gain-control options (populate + jumper)

The gain-set element for the PIC-op-amp path (FE-A) is a **jumper-selected** choice among
several on-board options, so we can compare:
- **MCP4531-103** digipot (**I²C**) — DesignA default.
- **MCP4131** digipot (**SPI**) — compare bandwidth/wiper parasitics.
- **Resistor bank + 74HC4052** analog mux — stepped gain, cheapest.
- **VGA Vgain** drive for FE-C/D: from a small **DAC (MCP4728)** *or* **RP2354 PWM+RC** —
  compare a real control-voltage VGA vs the digipot approach.

A **jumper block** selects which device sits in the OA2 gain node / drives the VGA `VGAIN`
pin; the I²C, SPI and `VGAIN` nets run to all candidates on the one board.

## 6. Pulser bench (populate-options)

- **Push-pull** IRLML6244/2244 + **TC4427A** (pic32arick default) **and** pads for a
  **single low-side N-FET** — fit either, compare edges/ring-down.
- **HV-rail select jumper:** USB **5 V** / on-board **boost** (footprint) / **external HV**
  (T7 header) — quantify amplitude vs depth. Pads for an **MD1213/TC6320** HV pulser too.
- **Damping** options: selectable series/parallel R (100–200 Ω) + the active-damping 2nd
  pulse.
- **TX drive** via **JP1** (PIC32 HS-PWM ⟷ RP2354 PIO), gate driver after the jumper.
- **T/R** populate-option: MD0100 / BAV99.

## 7. Measurement & self-test aids

- **SMA/coax taps** at: transducer node, LNA out, VGA/op-amp out, **ADC input**, TX gate.
  → inject from a signal generator / probe with a scope to characterise **gain, −3 dB BW,
  noise, linearity, ADC ENOB** of each block *independently* (no acoustics needed).
- **Loopback self-test mux** (pic32arick): switch the RX input between the transducer and
  an **internal DAC / injected reference**, so the chain can be characterised electrically.
- **Test points** on all rails, clocks (RP2354 12 MHz xtal, PIC PLL), SPI/I²C, RDY, TRIG,
  MCLR/PGC/PGD, HV rail.
- Generous **silkscreen** labelling every block, header pin, and jumper (M5).

## 8. Fabrication

- **4-layer** (clean analog ground/return; the ADC/op-amp noise story depends on it),
  size unconstrained. JLC-assemble the fine-pitch parts (RP2354, PIC32AK); hand-solder
  headers/jumpers/SMA. Fits the same LCSC/JLC flow as DesignA (PIC32A still the one
  consigned part — N2).

## 9. Parallel derisking with vendor eval hardware (do this first / cheapest)

Before (and alongside) the custom devkit, derisk the **highest-risk, silicon-level**
questions on off-the-shelf boards — this validates firmware + toolchain with zero PCB
spin:
- **PIC32A:** Microchip **Curiosity Platform (EV74H48A) + the PIC32AK GP-DIM**
  ([`pic32ak1216gc41064-gpdim-demo`](https://github.com/microchip-pic-avr-examples/pic32ak1216gc41064-gpdim-demo))
  → prove **ADC gap-free capture, op-amp gain, HS-PWM pulser timing**, and the **Linux
  XC-DSC + ipecmd** toolchain (resolves the "verify" items in `toolchain_designA.md`).
- **RP2354A:** a **Pico 2 / bare RP2354 module** → prove USB, PIO pulse/coded excitation,
  SPI ingest of a PIC A-line, DSP, WS2812.
- Then the devkit integrates the two and exercises the **analog** trade-offs (§4–§6) that
  the eval boards can't.

## 10. Path back to DesignA

Once the bench picks winners (LNA yes/no, which gain method, push-pull vs single, HV
level, 48- vs 64-pin, SRAM tier), **DesignA is the devkit with the losing blocks removed**
— keep the winning FE path (drop the other `JIN`/`JOUT` links and their parts), one gain
method, minimal pulser, 48-pin `3208`, small board. Because it's one board with jumpers
(not daughter-cards), down-spec = **depopulate + hard-wire the chosen jumpers**; the
schematic blocks carry straight over.

## Links
- Target product: [`../designA/README.md`](../designA/README.md) · concept/trade study:
  [`../pic32/README.md`](../pic32/README.md) · PIC32 flashing: [`../pic32/pic32.md`](../pic32/pic32.md).
- Toolchain: [`../designA/toolchain_designA.md`](../designA/toolchain_designA.md).
- Gain/LNA IC survey + prices: [`../../systems/afe-vga-ics.md`](../../systems/afe-vga-ics.md).
- Prior art: [kelu124/pic32arick](https://github.com/kelu124/pic32arick).

---

# PCB designer brief (shareable)

> **Standalone one-file version for handoff:** [`pcb-brief.md`](pcb-brief.md) — the same
> brief without the surrounding derisk-planning context. Keep the two in sync.

> Self-contained summary for a PCB designer. This board is an **evaluation / derisking
> platform** — the goal is **flexibility and measurability, not size or cost**. Everything
> is on **one board**; contested choices are selected with **jumpers** and every analog
> node has a **test point / SMA tap**.

## B1. What this board is

A single-channel **pulse-echo ultrasound** front-end dev board pairing two MCUs:
- **RP2354A** (Raspberry Pi, QFN-60, 7×7 mm) — USB-C host link, system manager, DSP,
  RGB LED, and **in-system programmer for the PIC** over ICSP. 2 MB in-package flash
  (no external flash chip). LCSC/JLC `C41378174`.
- **PIC32AK6416GC41064** (Microchip, 64-pin TQFP or VQFN) — the **analog capture engine**:
  three on-die 100 MHz op-amps (RX gain), a 12-bit 40 Msps ADC, HS-PWM (pulser + ADC
  trigger). Runs 3.0–3.6 V. *(Sourcing note: not currently LCSC-stocked — consign or
  hand-place; full datasheet DS70005592 in `pdfs/datasheets/`.)*

Signal flow: **transducer → T/R → [selectable RX front-end] → PIC32 ADC → SPI → RP2354 →
USB-C**; **RP2354/PIC HS-PWM → pulser → transducer**.

## B2. Board-level requirements

- **4-layer**, solid ground plane under the analog section; **size unconstrained**
  (favour clean layout + probe access over compactness).
- **All MCU pins broken out** to labelled 0.1″ headers (classic dev-board fan-out).
- **KiCad** source deliverable (schematic, PCB, gerbers, BOM CSV); fine-pitch parts
  (RP2354A, PIC32AK) placed for JLCPCB assembly, headers/jumpers/SMA hand-solderable.
- **Self-documenting silkscreen:** label every functional block, header pin, jumper, and
  test point.

## B3. Power & clocks

| Rail | Source | Notes |
|---|---|---|
| +5 V | USB-C VBUS | logic-side 5 V; also the **pulser rail** but **ferrite-isolated** (≈600 Ω @100 MHz) with local bulk+HF decoupling near the FETs |
| +3V3 DVDD | 3V3 LDO from 5 V | digital: RP2354, PIC digital, LED, logic |
| +3V3 AVDD | from 3V3 (ferrite/0 Ω link + **current-sense pads**) | analog: PIC AVDD, op-amp/ADC; keep quiet |
| VREF | **AVDD** (no external VREF pin on this family) | ADC full-scale; decouple per datasheet |

- **RP2354 QSPI_IOVDD must be 3.3 V** (internal flash). PIC needs its **VCAP** cap.
- **RP2354 USB clock:** 12 MHz crystal close to the device. **PIC** runs on internal
  FRC+PLL (no crystal). Per-pin 100 nF decoupling on every supply pin.

## B4. Programming / debug (two paths, shared net)

- **RP2354:** USB-C **BOOTSEL** button (wire **QSPI_CSn/SS → GND via ~1 kΩ**, pressed at
  power-up) + a **RUN** reset button. Flash via UF2.
- **PIC32:** **6-pin ICSP** header `1 MCLR/Vpp · 2 VDD · 3 GND · 4 PGED1 · 5 PGEC1 · 6 NC`
  **plus Tag-Connect TC2030-NL pads** (and consider the **off-center/alternated friction-
  fit holes** for solderless press-fit). **47 Ω series** on PGEC1/PGED1; **10 kΩ** MCLR
  pull-up, short MCLR net, no cap loading Vpp.
- The **RP2354 also connects to PGC/PGD/MCLR** so it can bit-bang LVP ICSP (one USB-C port
  programs both). Only one programmer active at a time → keep RP2354 pins Hi-Z when a
  PICkit drives the header (series R / firmware).

## B5. Inter-MCU interface (RP2354 ↔ PIC32)

| Bus | Signals | Purpose |
|-----|---|---|
| SPI | SCK, MOSI, MISO, CS | RP2354 master reads the captured A-line from the PIC (≤40 Mbps) |
| IRQ | RDY | PIC → RP2354 "line ready" |
| Trigger | TRIG | RP2354 → PIC ADC ext-trigger (used when RP2354 owns TX) |
| I²C | SDA, SCL | gain-control digipot/DAC + OLED |
| UART | TX, RX | debug/log (optional) |

## B6. Transmit / pulser (bench, populate-options)

- **Push-pull** default: **IRLML6244 (N)** + **IRLML2244 (P)** driven by a **TC4427A**
  dual gate driver (**8-pin**, 3V3→5V level-shift; **no internal dead-time** — from PWM or
  use a tied-gate totem; review-findings A5/A6/C1). **Footprint for a single low-side
  N-FET (2N7002)** as the minimal alternative.
- **Gate-drive source = JP1** (3-pin): **PIC32 HS-PWM** ⟷ **RP2354 PIO**; the TC4427A sits
  after JP1. Only one source at a time (other Hi-Z).
- **HV-rail select jumper:** USB **5 V** / on-board **boost** (footprint) / **external HV**
  header (T7). Also **pads for an MD1213 + TC6320** high-voltage pulser for later.
- **Damping:** selectable series/parallel resistor (100–200 Ω) at the transducer node.
- **T/R protection:** **MD0100** (footprint) with a **BAV99** clamp alternative.
- **TX↔ADC coupling:** the PIC HS-PWM that drives the gate can also emit the ADC start
  trigger (same counter) — route so this is exercisable; expose the trigger on a TP.

## B7. Receive front-end (jumper-selected, all on-board)

Common **RX node** (after T/R) and common **ADC node** (to a PIC ADC input). Each block
taps RX via `JIN_*` and drives the ADC node via `JOUT_*`; fit one JIN+JOUT pair to select
a path (unused blocks left un-jumpered → isolated). **Keep JIN links right at the RX node
to minimise stubs.**

| Path | Blocks to place | Route |
|---|---|---|
| FE-0 straight | (link only) | RX → ADC |
| FE-A PIC-opamp | route PIC OA1/OA2/OA3 in/out pins to the board | RX → OA1 fixed → OA2 (digipot) → ADC |
| FE-B LNA + PIC-opamp | **AD8432 / LMH6629 / OPA847** | RX → LNA → PIC OA → ADC |
| FE-C ext VGA | **AD8331** (QSOP-20) | RX → AD8331 → ADC |
| FE-D ext VGA (LP) | **AD8338** (LFCSP-16 3×3) | RX → AD8338 → ADC |

- **Gain-control options** (jumper-selected into the OA2 gain node / VGA Vgain):
  **MCP4531** digipot (I²C) · **MCP4131** digipot (SPI) · **74HC4052** resistor-mux ·
  **MCP4728** DAC or RP2354 **PWM+RC** for VGA Vgain.
- **ADC input conditioning (critical — single supply):** the front-end must present a
  signal **AC-coupled and biased to mid-rail VREF/2 ≈ 1.65 V**, scaled so the largest echo
  ≈ **2.6–2.8 Vpp** (never bipolar; ADC is 0→VREF). Provide the **mid-rail bias buffer**
  (PIC OA3 or a divider+buffer) and an **overrange clamp** (diodes to the rails) at the
  ADC input. Anti-alias: 2-pole RC (≈ (100 Ω+56 pF)×2) before the ADC.

## B8. Transducer & I/O connectors

- Transducer: **SMA/coax + 2×1 2.54 mm header + u.FL** (all three footprints; populate
  as needed).
- **SMA/coax taps** at: transducer node, LNA out, VGA/op-amp out, **ADC input**, TX gate —
  for signal-generator injection / scope probing (high-Z nodes: AC-couple / series-R the
  tap so it doesn't load the path).
- **Loopback self-test:** a mux/jumper to switch the RX input between the transducer and
  an injected reference (PIC DAC / SMA) to characterise the chain without acoustics.
- Optional: **RPi 40-pin** header (can be unpopulated pads), **SAO** header, **I²C OLED**
  (SSD1306), WS2812 RGB LED.
- **Test points** on all rails, VREF, clocks, SPI/I²C, RDY, TRIG, MCLR/PGC/PGD, HV rail,
  bias node.

## B9. Layout guidance (mixed-signal + HV pulse + 40 Msps ADC)

- **Ground:** one solid GND plane; keep the **RX analog return** clean and under the RX
  chain. Don't route SPI/PWM/USB/digital across the RX front-end.
- **AVDD/DVDD** split, joined at one point (ferrite/0 Ω) with the current-sense pads.
- **Pulser:** keep the TX switching loop (FETs ↔ decoupling ↔ transducer return) **tight
  and away from RX**; the T/R node is the analog boundary. Ferrite + bulk (100 µF) + HF
  (100 nF/10 nF) decoupling right at the FET/driver, as pic32arick.
- **RX:** short op-amp feedback loops; guard the high-Z op-amp inputs; minimise stubs on
  the shared RX and ADC nets; VREF + ADC-input decoupling per the datasheet.
- **Clock:** crystal + load caps hugging the RP2354, guard ring.
- **SMA taps** are for probing, not matched transmission lines (unless a tap is explicitly
  a 50 Ω injection point — mark it).

## B10. Deliverables

KiCad project (sch + PCB), schematic PDF, gerbers + drills, and a costed BOM CSV with
LCSC/Digikey part numbers. Note in the BOM which parts are **populate-optional** (the FE
variants, gain-control options, single-FET pulser, MD1213 pads, boost, OLED, 40-pin).

## B11. Reference material (in this repo / linked)

- PIC32AK **datasheet DS70005592** + **flash-prog-spec DS70005583** — `pdfs/datasheets/`
  (with `.md` siblings). Product brief DS70005582.
- Front-end/pulser/gain/ICSP prior art: **[kelu124/pic32arick](https://github.com/kelu124/pic32arick)**.
- Friction-fit ICSP header: **[microchip pic32ak…gpdim-demo](https://github.com/microchip-pic-avr-examples/pic32ak1216gc41064-gpdim-demo)**.
- Gain/LNA IC options + LCSC prices: [`../../systems/afe-vga-ics.md`](../../systems/afe-vga-ics.md).
- Target cheap product this feeds: [`../designA/README.md`](../designA/README.md).

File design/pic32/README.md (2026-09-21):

# design/pic32 — concept: PIC32A analog engine + RP2350 front-end

**Status:** concept / thoughts only (started 2026-09-18). No schematic yet.
This folder holds the *idea* of pairing a **Microchip PIC32AK…GC41064** ("PIC32A")
with the **RP2350** for *minus*. Datasheet/product brief:
[`pdfs/datasheets/PIC32AK1216GC41064-family-product-brief-DS70005582.pdf`](../../pdfs/datasheets/PIC32AK1216GC41064-family-product-brief-DS70005582.pdf).

> This is an **alternative architecture** to the current baseline (RP2350 + a
> separate high-speed ADC + separate VGA, per `requirements.md` §0 and
> `docs/claude/memory/0005-minus-direction.md`). It is not (yet) a decision — it's a
> trade study to capture the concept the owner raised.
>
> **Cheapest instantiation:** [`../designA/README.md`](../designA/README.md) — DesignA
> (RP2354A + PIC32A, 5 V N-FET pulser, digipot gain; active-IC BOM ≈ $3.7 / board ≈ $5).
>
> **PIC32 programming/flashing (practical):** [`pic32.md`](pic32.md) — ICSP header,
> PICkit/MPLAB, the two flashing paths, MCLR network.

---

## 1. The idea

Use the **PIC32A as the analog acquisition engine** and the **RP2350 as the open
USB/host front-end, manager, and DSP co-processor**:

- **PIC32A op-amps → the gain stage.** Its **three 100 MHz rail-to-rail op-amps**
  (100 V/µs slew, 1 mV offset) build the receive gain chain (LNA / filter / buffer)
  for a 3–4 MHz echo — no external VGA IC.
- **PIC32A ADC → digitize raw RF.** Its **two 12-bit ADCs at up to 40 Msps** sample
  the echo directly. It captures **one A-line (up to ~150 µs)** into its own SRAM.
- **PIC32A → RP2350 transfer.** The captured line is shipped to the RP2350 over a
  fast link (SPI, up to 40 Mbps on both parts).
- **RP2350 preprocesses + exposes.** RP2350 runs DSP (bandpass, Hilbert/envelope,
  decimation, matched filter), drives the OLED/RGB, and **exposes the data over its
  native USB-C** to the host — the role it already owns in the baseline.
- **RP2350 flashes the PIC.** RP2350 can program the PIC32A over its **2-wire ICSP**
  (bit-banged / PIO), so a **single USB-C port** boots and programs *both* chips: the
  RP2350 comes up via UF2 drag-and-drop, then flashes a bundled PIC image. No PICkit.

The division of labour is clean and plays to each chip's strength:

| Job | Chip | Why |
|-----|---|-----|
| HV pulse sequencing (coded excitation) | either | PIC32A HS-PWM (2.5 ns) + PTG, *or* RP2350 PIO — TBD |
| RX gain (LNA / filter) | **PIC32A** | 3× 100 MHz op-amps on-die |
| Digitize raw RF | **PIC32A** | 12-bit **40 Msps** ADC on-die |
| Buffer 1 line (~150 µs) | **PIC32A** | ADC → its SRAM, then burst out |
| USB host link | **RP2350** | PIC32A has **no USB**; RP2350 has native USB |
| Open reflash (UF2) | **RP2350** | RP2350 = open front door; flashes the PIC over ICSP |
| DSP / envelope / matched filter | **RP2350** (and/or PIC32A DSP) | both have FPU/DSP; RP2350 has more RAM |
| OLED / RGB / badge UI | **RP2350** | PIO for WS2812; existing plan |

## 2. Why this is *relevant* — the numbers line up

The PIC32A's on-die analog is the whole point: it **collapses the external ADC
(open item ADEC) and the external VGA (A3) into the MCU itself**.

- **Raw-RF sampling (P3/P4).** minus needs ≥ 16 MSps (target 20–30), ≥ 10-bit.
  PIC32A: **40 Msps, 12-bit** — clears both with headroom, and would even allow a
  higher fc later.
- **Analog bandwidth (P2).** Op-amps at **100 MHz** GBW / 100 V/µs comfortably pass
  a 3–4 MHz band.
- **150 µs capture vs SRAM.** This part (PIC32AK3208GC41064) has **8 KB SRAM**
  (Digikey: 8K×8) — smaller than the family max, so the depth math is tight:
  - At **20 Msps**: 150 µs → 3 000 samples × 2 B = **6 KB** ✓ fits (leaves ~2 KB for
    stack/vars — code runs from flash). Good match for the owner's "up to 150 µs".
  - At **40 Msps**: 150 µs → 12 KB ✗ **does not fit** in 8 KB. Full-rate grabs are
    capped at ~**80–100 µs** (or capture decimated / windowed). RP2350 (far more RAM)
    buffers longer lines and multiple lines. ⇒ **the PIC grabs one line within 8 KB and
    bursts it out; deep/multi-line buffering stays on the RP2350.**
- **3.3 V everywhere.** PIC32A runs 3.0–3.6 V, same domain as RP2350 → simple SPI
  interconnect, shared 3V3 rail.
- **Coordination built in.** HS-PWM has "flexible trigger configuration for ADC
  triggering" and there's a Peripheral Trigger Generator (PTG, a CPU-independent
  state machine) — good for firing TX and starting the ADC deterministically.

## 3. Trade-off vs the current baseline

**Baseline:** RP2350 + external high-speed ADC (on PIO) + external VGA (e.g. AD8338)
+ T/R + unipolar pulser.

**This concept:** RP2350 + PIC32A (ADC + op-amp gain in one) + T/R + pulser.

### Potential wins
- **Fewer analog ICs / smaller board (DP1–DP3).** One PIC32A replaces *both* the
  external ADC and the external VGA/LNA. Could be a net part-count reduction even
  though it adds a second MCU.
- **No PIO-clocked external-ADC bus to design.** The trickiest part of the baseline
  (gap-free parallel ADC capture over PIO+DMA, C1b) moves on-die into the PIC32A.
- **Better ADC than the cheap-ADC shortlist** (40 Msps/12-bit vs 20 Msps/10-bit
  candidates) — more dynamic range and future headroom.
- **Rich extra analog for free:** 3 comparators + 12-bit DACs (threshold/echo
  detect, gain-node bias, offset trim), current sources, HS-PWM for the pulser.

### Costs / risks / tensions
- **⚠️ Open-toolchain tension (anti-requirement N1 / S4).** PIC32A builds with
  Microchip's **MPLAB X + XC-DSC** (proprietary, closed; optimized tiers licensed) —
  **not** an open GCC flow like RP2350's pico-sdk (DP4). Mitigation: ship a
  **prebuilt PIC image** that the RP2350 flashes over ICSP, so *using/reflashing* the
  badge stays fully open (UF2 → RP2350 → ICSP → PIC). Only attendees who want to
  **modify the PIC firmware** need the closed toolchain. This is the single biggest
  philosophical cost and must be a conscious, documented trade (see §19 N1, N5).
- **Gain is set by external feedback resistors, not a built-in PGA.** For the PIC32AK
  op-amps, unity-gain mode needs no external parts; for gain you **disable unity-gain
  and add external R** (no confirmed internal GSEL resistor ladder like some dsPIC33/
  PIC24 — *verify in the datasheet; if present it'd give register-set gain with zero
  extra parts*). Since **TGC is not required** (see §3b), this is only a *per-line
  settable* gain — a digital pot / MDAC in the feedback path, cheap and simple.
- **Two MCUs = more firmware surface.** Two codebases, an inter-MCU protocol, and a
  boot/flash sequence to maintain. Against DP3 (simplicity) at the *firmware* level,
  even if the *hardware* gets simpler.
- **Sourcing / cost unknown (anti-req N2).** Need **LCSC stock + price at qty 20–50**
  and JLCPCB assemblability confirmed (see `docs/claude/memory/0006-pricing-basis`).
  Seen at RS/Digikey (TQFP-64 `-I/PT`, QFN `-I/M7`); **LCSC availability TBD** — if
  not JLCPCB-stocked, that's an N2 strike against it.
- **SRAM is small (8 KB).** Fine for one ~150 µs line at 20 Msps (6 KB); *not* enough
  for 150 µs at full 40 Msps, nor for deep multi-line buffering — that stays the
  RP2350's job (which has far more RAM). See §2.
- **Departs from DP5 (reuse).** None of the owner's proven designs
  (un0rick/lit3rick/pic0rick) use a PIC32A analog engine — this is new ground, so it
  carries integration risk the reuse principle was meant to avoid.

## 3a. BOM simplicity & the cheapest pulser

**Is the BOM relatively simple?** Yes — competitively so, because the PIC32A folds the
two costliest external analog parts into itself:

| Block | Baseline (RP2350 route) | PIC32A concept |
|---|---|---|
| ADC | external high-speed ADC IC | **on-die (40 Msps)** — removed |
| RX gain / LNA / VGA | external VGA (e.g. AD8338) | **on-die op-amps** — removed |
| MCU flash | RP2350 needs **external QSPI flash** | PIC32A has internal flash; RP2350 still needs its flash (or use RP2354 = stacked flash) |
| Clock | RP2350 crystal | PIC32A internal FRC+PLL (no xtal); RP2350 xtal for USB |
| Controller | RP2350 | RP2350 **+ PIC32A** (adds one IC) |

Net: **delete the external ADC + VGA, add the PIC32A** → active-IC count comparable or
lower, and layout is easier (no PIO-clocked parallel-ADC bus to route).

**Price check (2026-09-18):** the PIC32A is **cheap** — Digikey lists
`PIC32AK3208GC41064-I/PT` (TQFP-64, 32 KB flash, 8 KB RAM) at **$1.91 / 1, $1.73 / 25,
$1.58 / 100**, **498 in stock**, 7-week factory lead. So it replaces the external
**ADC + VGA for < $2** — a clear win for DP2/cheapest, *better* than the baseline
"cheapest" active-IC BOM (≈ $16 with AD8338 + cheap ADC + RP2350).

**LCSC / JLCPCB availability (checked 2026-09-18): NOT confirmed — likely not stocked
yet (N2/B2 risk).** LCSC site-restricted search returned no listing, and JLCPCB's parts
library search surfaced nothing for `PIC32AK`; RS/Mouser list the family but mostly
out-of-stock / 2026 lead. It's a new part (2024 product brief). **Consequence:** for the
project's LCSC/JLCPCB assembly flow it would currently be a **consigned / "extended"
part** (self-supplied, feeder fee) or you source from **Digikey** and hand-place. This
is the main open sourcing risk — re-check `jlcpcb.com/parts` + the LCSC BOM tool
periodically, as new Microchip parts do get added over time.

**Cheapest pulser — 5 V PIO → transistor gating 5 V (= `options.md` U0).** Viable as
the low-cost baseline. Get four things right:
- **Topology / gate drive.** GPIO/PIO is 3.3 V → a **logic-level N-FET low-side**
  (2N7002-class) switches cleanly. Pushing +5 V high-side (P-FET) gives only ~−1.7 V
  Vgs from a 3.3 V swing — marginal; needs a logic-level P-FET or a level shift. Low-side
  N-FET is the simple answer.
- **Edge speed at 3–4 MHz.** Half-period ~125–165 ns ⇒ want edges < ~30 ns. A *small*
  FET (Ciss ~30–50 pF) can be driven straight from a pin (~20 ns) for a low-amplitude
  demo; for real punch add a **small gate driver** (hence T3's "MOSFET + gate driver").
- **Amplitude is low.** 5 V = weak pulse; fine for a superficial (1–4 cm) muscle demo
  with front-end gain + averaging + coded excitation. Keep the **HV node on a header
  (T7)** so higher HV can be jumpered in later.
- **Keep the T/R clamp (A2)** — even at 5 V the RX/op-amp inputs need protecting from
  the TX edge (a couple of diodes suffice at 5 V).
- **Synergy:** the PIC32A's high-current I/O + **2.5 ns HS-PWM with ADC trigger** can
  drive the gate with cleaner, better-timed (and coded/chirp) edges than a bare GPIO —
  a point in favour of letting the PIC own TX sequencing.

## 3b. Gain stage — no TGC, just per-line settable gain

**Decision (owner, 2026-09-18): TGC is NOT required.** No need to vary gain *during* a
line (depth-dependent ramp). Instead: **the user sets a fixed gain, and can change it
between firing lines.** This is much simpler than a VGA + fast DAC ramp, and it removes
the hardest part of the analog front-end (gain/depth timing sync). It supersedes the
TGC intent in `requirements.md` F6/A3/P8 — see the note there.

**What "set a gain between lines" needs:** a gain that is *static within a line* but
*digitally re-settable between lines* by firmware. On the PIC32A the op-amp gain is set
by **external feedback resistors** (unity-gain mode = no external parts; for gain,
disable unity-gain and add Rf/Rin). To make that gain programmable between lines,
options in rough order of cost/simplicity:

| Option | How | Cost | Notes |
|---|-----|---|---|
| **Digital potentiometer / MDAC in feedback** *(fits the owner's "DAC controls gain")* | Replace the feedback (or input) resistor of a PIC32A op-amp with a digipot (e.g. MCP41xxx, SPI) or a multiplying DAC; firmware sets the code between lines | ~$0.5–1 | Smooth/many-step gain, set over SPI/I²C by either MCU. **This is the recommended fit.** |
| **Resistor bank via analog mux/GPIO** | An analog switch selects among a few fixed feedback resistors → 3–4 discrete gain steps | ~$0.2–0.5 | Cheapest; stepped gain is fine if the user only needs a few levels between lines |
| **External VGA/PGA IC** | A real gain-controlled amp (e.g. AD8338) driven by a control voltage/DAC | ~$2–4 | Reintroduces the part we deleted; only worth it if the op-amps aren't good enough |

> **Note on "DAC controls op-amp gain":** an op-amp's gain lives in its **resistor
> ratio**, so the right primitive is a *digitally-controlled resistor* (digipot/MDAC)
> in the feedback path — not a DAC voltage into a summing node. A DAC voltage sets gain
> only in a true multiplier/VGA (e.g. AD8338), which is the external part we're avoiding.
> The PIC32A's on-die 12-bit DAC is still useful for **offset/bias trim** or a
> comparator threshold, not for setting op-amp gain directly.

**LNA-first alternative (the owner's other idea).** The PIC32A op-amps are
general-purpose 100 MHz parts; their input **noise** isn't specified as low. For weak
echoes (a 5 V pulser gives a small signal), put a **fixed low-noise LNA as the first
stage** to set the noise floor, then the settable-gain op-amp stage, then the ADC:

`transducer → T/R clamp → [fixed LNA] → settable-gain op-amp → anti-alias → ADC`

The LNA adds one cheap low-noise op-amp (~$0.3–1) but improves sensitivity/SNR — good
insurance given the low TX amplitude. Whether it's *needed* depends on the PIC32A
op-amp's measured noise vs the echo level (open item). Baseline can start **without**
it (op-amp gain only) and add it if SNR limits the demo.

**Verify:** does the PIC32AK op-amp have an internal programmable-gain (GSEL) resistor
ladder like some dsPIC33/PIC24 parts? The family notes point to *external* resistors,
but if a GSEL ladder exists it would give register-set per-line gain with **zero extra
parts** — the ideal outcome. Confirm in the full datasheet / op-amp FRM.

## 3c. Chip choice — package (pins) & program memory

The family comes in **three pin counts** and several **flash/RAM tiers**; pin count and
memory are independent axes of the part number
(`PIC32AK`**`<flash><ram>`**`GC41`**`<pins>`**, e.g. `3208…064` = 32 KB flash / 8 KB
RAM / 64-pin; `1216…` = the 128 KB / 16 KB top of family).

### Pins: 36 vs 48 vs 64
| Pins | Package | I/O / analog | Fit for *minus* |
|---|---|---|---|
| **36** | VQFN | fewest | Smallest, but tight — after the RX analog pins + SPI + ICSP/reset + a couple of handshake lines there's little spare. Only if a pin-budget pass confirms it fits. |
| **48** | TQFP / VQFN | mid | **Sweet spot.** Comfortable for one RX channel + SPI-to-RP2350 + ICSP + handshakes, still small. |
| **64** | TQFP / VQFN | 49 I/O, ≤22 analog | Generous headroom / test points, but larger. Less needed here since the **RP2350 owns the 40-pin extension header** (C5) — the PIC's I/O demand is modest. |

Rough pin budget (single channel): ~3–6 analog (op-amp in/out + echo in; the ADC can
tap the op-amp output internally) + SPI (4) + ICSP/reset (3, muxable) + IRQ + TRIG
(+ optional UART 2) + optional pulser-gate (1) ≈ **12–16 pins used** → **36 is
borderline, 48 is safe.** Recommend **48-pin** unless a layout pass proves 36 works.

### Program memory (flash) & the real lever: SRAM
- **Flash:** the PIC's firmware is small — ADC capture into RAM, SPI burst-out, TX
  sequencing, maybe light DSP. That's tens of KB at most, so **32 KB flash is ample**;
  only reach for a bigger tier if on-PIC DSP grows. *Confirm once firmware exists.*
- **SRAM is the binding constraint, not flash** (see §2): it sets how much of an A-line
  the PIC can hold.
  - **8 KB (the cheap `3208`)** → ~6 KB capture = **150 µs @ 20 Msps** ✓ (but not
    150 µs @ 40 Msps).
  - **16 KB** → **150 µs @ 40 Msps** (12 KB) fits. The cheapest way to 16 KB is the
    **`6416` tier (64 KB flash / 16 KB RAM)** — no need to jump to the 128 KB `1216`.
- Known flash/RAM tiers: **`3208`** (32/8), **`6416`** (64/16), **`1216`** (128/16).
- **Recommendation:** start with **`PIC32AK3208GC41048`** (32 KB / 8 KB, 48-pin) —
  cheapest, covers 150 µs @ 20 Msps. If full **40 Msps × 150 µs** is needed, step to
  **`PIC32AK6416GC41048`** (64/16, same 48-pin) rather than the 128 KB part. (Confirm
  the exact intermediate flash/RAM tiers
  and per-SKU prices on the Microchip product selector / LCSC.)

### Footprint — keep it as small as feasible (DP1)
Each pin count is offered as **TQFP** (`-…/PT`, gull-wing leads) *and* **VQFN**
(`-…/M7`, leadless). Approximate body sizes (confirm against the package drawing):

| Part / pins | TQFP body (0.5 mm pitch) | VQFN body |
|---|---|---|
| 36-pin | — | **≈ 5 × 5 mm** (smallest) |
| 48-pin | ≈ 7 × 7 mm (≈ 9 × 9 w/ leads) | **≈ 6 × 6 mm** |
| 64-pin | ≈ 10 × 10 mm (≈ 12 × 12 w/ leads) | ≈ 9 × 9 mm |

Guidance for the smallest board:
- **VQFN beats TQFP** on area (no gull-wing leads) — but it's **bottom-terminated /
  leadless**, which anti-req **N2** flags to avoid *where avoidable* (harder to hand-
  solder / visually inspect). **However, the board already carries a QFN RP2350**, so
  it's reflow/JLC-assembled anyway → a VQFN PIC adds no new assembly requirement. ⇒ For
  a JLC-assembled badge, **48-pin VQFN (~6×6 mm)** is the small-but-adequate pick;
  offer **48-pin TQFP** as the hand-solder-friendly alternate; **36-pin VQFN (~5×5 mm)**
  only if the pin budget (§3c) is confirmed and minimum area is paramount.
- **Shrink the RP2350 too:** with the PIC32A doing the ADC + analog, the RP2350 no
  longer needs a wide parallel-ADC GPIO bus → the **RP2350A (QFN-60, 7×7 mm)** likely
  suffices instead of the larger **RP2350B (QFN-80, 10×10 mm)**, and **RP2354A**
  (QFN-60, 7×7, 2 MB stacked flash) *also deletes the external QSPI flash chip* — both
  a smaller MCU and one fewer part. Re-check the RP2350 GPIO budget once the interconnect
  (§3d) is fixed.
- **RP2354A confirmed (datasheet §14.3, §2.1):** 2 MB **in-package** flash (a stacked
  Winbond W25Q16JVWI die), QFN-60, **pin-identical to RP2350A**, 30 GPIO / 4 analog. So
  **no external QSPI flash chip** on the BOM/PCB. **On LCSC/JLC: C41378174, ~$1.27, in
  stock** (JLC-assemblable ✓). Caveats: **QSPI_IOVDD must be 3.3 V**;
  an *extra* QSPI device (more flash / PSRAM) can still hang off the QSPI bus using a
  Bank-0 GPIO as chip-select if ever wanted.
- **BOOTSEL button (RP2354A):** the six QSPI pads (incl. **QSPI_CSn / SS**) are still
  bonded to package pins even though the flash is internal, and BOOTSEL is entered by
  **pulling QSPI_CSn low at reset/power-up** ("harmlessly selects the internal flash
  die"). ⇒ Wire the BOOTSEL button exactly as on a flashless RP2350A/Pico: **from the
  QSPI_CSn (SS) pin to GND, via a ~1 kΩ series resistor**, pressed during power-up. To
  enter BOOTSEL without a power cycle, pair it with a **RUN (reset) button** (hold
  BOOTSEL, pulse RUN low). On the badge these can be small tact switches or just test
  pads if we minimise buttons.
- Board size is ultimately also set by the **connectors** (USB-C, SMA, the 40-pin
  header) and test points — but on the silicon side, two ~6–7 mm QFNs is compact.

## 3d. RP2350 ↔ PIC32A interconnect

Division of roles (§1): **RP2350 = manager / USB / programmer / DSP; PIC32A = capture
engine.** So the RP2350 is the SPI **master** and the PIC's **programmer**, and the PIC
signals when a line is ready. Proposed signals:

| Link | Signals | Dir | Purpose |
|---|---|-----|---|
| **ICSP (program + reset)** | `MCLR`, `PGC`, `PGD` | RP2350 → PIC | RP2350 flashes the PIC over 2-wire **LVP ICSP** (PIC32 Flash Programming Spec DS60001145); `MCLR` doubles as the **reset** line so RP2350 can hold/boot the PIC. One USB-C port programs both (RP2350 via UF2 → then flashes the PIC). |
| **SPI (data)** | `SCK`, `MOSI`, `MISO`, `CS` | RP2350 master ↔ PIC slave | Burst the captured A-line out (PIC SPI ≤ 40 Mbps; ~6–12 KB ≈ 1–2.5 ms between pulses). Also carries config/commands. |
| **Data-ready / IRQ** | `RDY` | PIC → RP2350 | PIC raises it when a line is captured → RP2350 reads it (avoids polling). |
| **Trigger / sync** | `TRIG` | RP2350 → PIC | Hardware start for acquisition; if RP2350 owns TX (PIO), this fires the PIC's ADC via its external-trigger input so TX and RX stay time-aligned. (If the **PIC** owns TX via HS-PWM+PTG, `TRIG` just means "go" and TX↔ADC sync is on-chip.) |
| **UART (optional)** | `TX`, `RX` | ↔ | Cheap debug/log + low-rate control channel independent of SPI; PIC can emit logs the RP2350 forwards to USB. Drop it to save 2 pins if tight. |
| **Power** | shared **3V3**, GND | — | Both run 3.0–3.6 V → single rail; each with its own decoupling (+ PIC `VCAP`). |

Notes:
- **Pin reuse:** the ICSP pins (`PGC`/`PGD`) are muxed GPIO on the PIC — they can double
  as run-time handshake/SPI lines after programming, which helps the 36/48-pin budget.
- **Who is SPI master:** RP2350-master + PIC `RDY` interrupt is the clean default (the
  manager pulls data from the smart peripheral). PIC-as-master (pushing) is possible but
  complicates RP2350-side buffering.
- **Minimal set** if pins are tight: ICSP(3) + SPI(4) + `RDY`(1) + `TRIG`(1) = **9
  lines** (UART optional).

## 4. Confirmed part facts (from the product brief, DS70005582)

PIC32AK…GC41064 family:
- **Core:** 32-bit, **DC–200 MHz**, single+double-precision **FPU**, DSP (dual 72-bit
  accumulators), 2 KB I-cache. **3.0–3.6 V**, −40…+125 °C, AEC-Q100 Grade 1.
- **This part (PIC32AK3208GC41064):** **32 KB flash**, **8 KB SRAM** (Digikey: 8K×8),
  **64-pin** (TQFP `-I/PT` / QFN `-I/M7`), 49 I/O. Price **$1.91/1, $1.73/25, $1.58/100**
  (Digikey, 498 in stock, 7-wk factory lead). *LCSC/JLCPCB availability still TBD.*
- **ADC:** **two 12-bit ADCs, up to 40 Msps** (**ENOB ≈ 10.5 bits**, not full 12), up to
  22 analog input pins, 20 setting channels (single-ended or differential), oversampling /
  integration / window / single modes, per-channel digital comparator, 2nd-order filter
  accumulators on 3 channels, band-gap ref + temp sensor.
- **ADC input range (single supply):** reference is **AVDD (~3.3 V)** — **no external
  VREF+ pin on this family** (corrected 2026-09-21). **Single-ended: 0 → VREF** (LSB ≈
  0.8 mV); pins must stay 0–3.3 V. **Differential:** the "~±VREF/4" figure is from generic
  dsPIC33A docs and is **not in the PIC32AK datasheet — verify**; single-ended is the safe
  larger window. ⇒ 0-centred RF must be **biased to VREF/2 (~1.65 V)** and scaled to
  ~2.6–2.8 Vpp (DesignA §5a). *Full detail in the datasheet DS70005592 (mirrored in `pdfs/datasheets/`).*
- **ADC↔TX trigger:** the **HS-PWM ADC-trigger** + **PTG** + ADC **window/gate** modes
  let the pulser-driving PWM also start the ADC off the **same counter** → phase-locked,
  ~2.5 ns, zero-jitter acquisition when the PIC owns TX (DesignA §5b).
- **Op-amps:** **three rail-to-rail** op-amps — **100 MHz GBW / 100 V/µs slew in
  High-Power mode only** (Low-Power = **50 MHz / 10 V/µs**); offset **±1 mV typ, ±3 mV
  max**; **input-noise density is unspecified** in the datasheet ⇒ whether an LNA is needed
  is an open, bench-only question. *(GBW/gain limits the usable gain at 3–4 MHz — see
  `../devkit/review-findings.md` B1.)*
- **Comparators/DACs:** three 5 ns comparators with **12-bit PDM DACs** (slope comp,
  one output buffer).
- **Current sources:** four 10 µA constant + four programmable.
- **HS-PWM:** four generators (8 outputs), **2.5 ns** resolution, ADC-trigger.
- **Comms:** 3× SPI (**up to 40 Mbps**, 16-B FIFO, I²S), 2× I²C, 3× UART (LIN/DMX/
  ISO7816/IrDA), 2× SENT. **No USB** — the reason to pair with RP2350.
- **Other:** QEI, 4× CLC, PTG (peripheral trigger generator), CRC, ECC flash/RAM,
  2-wire ICSP + JTAG debug.
- **Variants (see §3c):** pin counts **36 / 48 / 64** (VQFN `-…/M7` or TQFP `-…/PT`);
  flash/RAM tiers **`3208`** (32/8), **`6416`** (64/16), **`1216`** (128/16); pins and
  memory are independent axes of the part number. Package bodies ≈ 36-VQFN 5×5,
  48-VQFN 6×6 / 48-TQFP 7×7, 64-VQFN 9×9 / 64-TQFP 10×10 mm.

## 5. Open questions / to verify

- [x] **Price** — Digikey ~$1.6–1.9 (32 KB flash / 8 KB RAM / TQFP-64). Cheap. ✓
- [~] **LCSC stock + JLCPCB assembly (N2)** — checked 2026-09-18: **not found on
      LCSC/JLCPCB** (new part; Digikey has it). ⇒ consigned/"extended" part for JLC
      assembly, or Digikey + hand-place. Main sourcing risk; re-check periodically.
- [ ] **Package/footprint (§3c):** smallest feasible → 48-pin **VQFN ~6×6 mm** (board is
      already QFN-assembled); consider **RP2350A/RP2354A (QFN-60, 7×7)** to shrink the
      MCU + drop the external flash.
- [ ] **Per-line settable gain** (TGC dropped): digipot/MDAC in feedback vs resistor-mux
      steps vs (verify) an internal GSEL op-amp ladder. Confirm the op-amp has an
      internal PGA ladder — if so, zero extra parts.
- [ ] **Op-amp noise / input range** — good enough alone, or add a fixed **LNA** first
      stage for weak 5 V-pulser echoes (§3b)?
- [ ] **Package/pin choice** (§3c): confirm the pin budget → **48-pin** (safe) vs
      **36-pin** (smallest, borderline).
- [ ] **Memory tier** (§3c): `3208` (32 KB/8 KB, 150 µs @ 20 Msps) vs a 16 KB-RAM tier
      (150 µs @ 40 Msps). Flash ~32 KB likely ample; SRAM is the lever.
- [ ] **Who sequences TX** (PIC32A HS-PWM+PTG vs RP2350 PIO) and how coded excitation
      + acquisition stay time-aligned across two chips (drives the `TRIG` line, §3d).
- [ ] **Inter-MCU protocol** (§3d): SPI framing, RP2350-master + PIC `RDY` IRQ, PRF vs
      transfer budget (6–12 KB over 40 Mbps ≈ 1–2.5 ms — fine between pulses).
- [ ] **ICSP-from-RP2350** feasibility (2-wire LVP ICSP timing over PIO, per DS60001145)
      so one USB port programs both; `MCLR` also as the reset line.
- [ ] Net **BOM & board-area** vs baseline — is it actually simpler/cheaper once the
      second MCU is counted?
- [ ] Reconcile with **DP4** ("controller is RP2350") and **DP5** (reuse) — is the
      PIC32A a *peripheral* (baseline unchanged) or a *co-controller* (revisit DP4)?

## 6. Sources

- Microchip product page — PIC32AK3208GC41064:
  https://www.microchip.com/en-us/product/pic32ak3208gc41064
- Family product brief DS70005582 (mirrored in `pdfs/datasheets/`, with `.md` sibling):
  https://ww1.microchip.com/downloads/aemDocuments/documents/MCU16/ProductDocuments/ProductBrief/PIC32AK1216GC41064-Family-Product-Brief-DS70005582.pdf
- Variants: Microchip product pages for `…GC41048` (48-pin) / `…GC41036` (36-pin) /
  `…GC41064` (64-pin), and RS/Digikey listings (pin & 32 KB–128 KB flash options).
- Price: Digikey `PIC32AK3208GC41064-I/PT` (2026-09-18).
- PIC32 Flash Programming Specification DS60001145 (for RP2350→PIC ICSP/LVP).

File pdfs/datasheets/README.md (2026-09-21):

# pdfs/datasheets — component datasheets

Datasheets / app-notes for candidate ICs (esp. pulser options — see
[`../../analysis.md`](../../analysis.md)).

| File | IC / doc | Role |
|---|---|---|
| `MD1213_pulser-driver.pdf` | Microchip MD1213 | 3-state HV MOSFET driver (single-channel ultrasound pulser driver). |
| `MD1213DB1_pulser_demoboard_MD1213+TC6320.pdf` | MD1213DB1 demoboard | **Reference design**: MD1213 + TC6320 = ±100 V, 2 A single-channel pulser (the un0rick/pic0rick/IUP pulser). |
| `AN-H53_HV-pulser-circuits.pdf` | Microchip AN-H53 | HV pulser circuit app note (MD1210/MD1213). |
| `TUSS4470_AFE.pdf` | TI TUSS4470 | Integrated single-channel AFE (TX H-bridge + LNA + log-amp + envelope), 30 kHz–1 MHz. |
| `PIC32AK1216GC41064-family-product-brief-DS70005582.pdf` | Microchip PIC32AK…GC41064 family | 200 MHz PIC32A MCU (FPU+DSP) with **2× 12-bit 40 Msps ADC**, **3× 100 MHz rail-to-rail op-amps**, 3 comparators + 12-bit DACs, HS PWM. Concept: pair with RP2350 as the analog capture engine → `design/pic32/`. |
| `PIC32AK1216GC41064-family-datasheet-DS70005592.pdf` | Microchip PIC32AK…GC41064 family | **Full datasheet** (DS70005592) — ADC input range/VREF, op-amp specs, HS-PWM/PTG ADC triggering, pinouts, electrical. The authoritative reference for `design/pic32/` + DesignA. |
| `PIC32AK1216GC41064-family-flash-programming-spec-DS70005583.pdf` | Microchip PIC32AK…GC41064 family | Flash Programming Spec (DS70005583) — ICSP/LVP entry sequence + timing (for the RP2354→PIC bit-bang programmer and PICkit); see `design/pic32/pic32.md`. |

Not mirrored (host blocked download — links):
- **TC6320** (Microchip HV P/N MOSFET pair, ±100 V, 2 A) — covered in MD1213DB1; product page: microchip.com/TC6320.
- **STHV748** (ST quad ±90 V, ±2 A, 3/5-level pulser **with integrated T/R switch**) — st.com/en/switches-and-multiplexers/sthv748s.html.

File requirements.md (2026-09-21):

# minus — Requirements (draft)

**Status:** draft v0.3, 2026-09-17. Grounded in [`docs/claude/memory/0001-project-scope.md`],
the survey in [`systems/`](systems/README.md), and the route/pulser analysis in
[`analysis.md`](analysis.md). Requirement values marked **TBD** need a decision
(see §4). Priorities use MoSCoW: **[M]** must, **[S]** should, **[C]** could, **[W]** won't-yet.

**v0.2 firm requirements (from the owner):** smallest practical board, cheapest BOM,
design as simple as possible, and **RP2350 as the MCU** (resolves TBD-7; host link is
its native USB, resolving TBD-4). See **Design principles** below and §10.

**v0.3 firm requirements (from the owner):** **non-clinical (NDT)** use (TBD-1);
target transducer **3–4 MHz** (TBD-2); **unipolar** pulser for simplicity (TBD-3);
**A-mode core, M-mode optional** (TBD-5); **drive BOM as low as possible** — actively
explore cheap options (TBD-6).

**v0.3 context (from the owner):** minus is the hands-on device for a **workshop at an
ultrasound conference**. It keeps a conference **"badge" form factor**, on a limited
budget (many units), and must let attendees **experiment** — e.g. try **coded/encoded
excitation** (see §8 T4). Example workshop topic: **muscle-contraction monitoring**
(A-/M-mode of superficial muscle). The **piezo transducer is provided** with the kit
(a known ~3–4 MHz single element), so the front-end can be tuned to it.

## 0. Design principles (overriding [M])

- **DP1 — Small:** smallest practical single board.
- **DP2 — Cheap:** minimise BOM cost and part count.
- **DP3 — Simple:** simplest design that meets the functional requirements; fewest
  ICs, jelly-bean parts, easy hand-assembly and reproduction.
- **DP4 — RP2350 MCU:** the controller is the Raspberry Pi **RP2350** (see §10).
- **DP5 — Derisk by reuse:** prefer **proven building blocks from the owner's own,
  validated designs** — echomods/**Murgen**, **un0rick**, **lit3rick**, **pic0rick**
  (the owner has built these and is happy with their performance). Reuse their pulser,
  T/R, VGA/TGC, ADC-capture, and PIO patterns rather than inventing new ones. Design
  files are on disk in [`design/`](design/README.md).

These principles are tie-breakers: when two designs meet the functional requirements,
prefer the smaller / cheaper / simpler one, and the one that **reuses proven blocks**.

> **Architecture note (RP2350 + ADC).** The RP2350's on-chip SAR ADC is **12-bit,
> 500 kSps** — far too slow for **3–4 MHz** raw RF (P3 needs ≥ ~16–30 MSps). So minus
> uses **RP2350 + one external high-speed ADC** clocked into the RP2350 **PIO** (the
> pic0rick pattern on RP2350). At 3–4 MHz a ~20–30 MSps 10–12-bit ADC is enough —
> cheaper and smaller than pic0rick's 65 MSps part, which helps DP1–DP3/BOM. *If the
> raw-RF requirement were relaxed to ≤~1 MHz envelope/ToF, the internal ADC could be
> used and the board gets much simpler — the alternative, not the current baseline.*

---

## 1. Purpose & scope

**minus** is a **minimal, single-channel, low-cost, open** ultrasound pulse-echo
platform, built as a **conference-workshop badge**. It generates a high-voltage
excitation on one (provided) piezo transducer, amplifies and digitizes the returning
echo, and delivers raw data to a host for processing. The workshop lets attendees
learn and experiment — e.g. **muscle-contraction monitoring** (A-/M-mode) and **coded
excitation**.

**In scope:** single-element A-/M-mode acquisition (raw RF) with a provided ~3–4 MHz
piezo; depth-variable gain; programmable/coded excitation; host-side processing;
badge form factor; low, workshop-scalable BOM.
**Out of scope (this version):** multi-element phased-array beamforming, on-board
real-time B-mode reconstruction, clinical use/certification (see §16). For things we
actively **do not** want — closed toolchains, vendor lock-in, un-reproducible parts —
see the **anti-requirements in §19**.

## 2. Intended use & users

- **Primary use:** research, education, experimentation, and NDT — a hackable,
  reproducible single-channel ultrasound front-end (in the un0rick/pic0rick lineage).
- **Classification:** **non-clinical** — **NDT (non-destructive testing)**,
  research and education. Not a medical device (§16).
- **Users:** **ultrasound-conference workshop attendees** (and afterwards makers,
  students, researchers, NDT experimenters). Assume a range of skill; the device and
  its host software must be approachable for a guided workshop yet hackable for
  experimentation.

## 3. Definitions & references

- **A-mode** amplitude vs depth (1-D); **B-mode** 2-D image; **TGC** time-gain
  compensation; **T/R** transmit/receive switch; **AFE** analog front end; **PRF**
  pulse-repetition frequency; **fc** transducer centre frequency.
- References: [`analysis.md`](analysis.md), [`systems/by-ic.md`](systems/by-ic.md),
  [`systems/literature.md`](systems/literature.md), design files in [`design/`](design/README.md).

## 4. Assumptions & open decisions (must be resolved to freeze v1.0)

**Resolved (owner decisions):**
- **TBD-1 → RESOLVED:** **non-clinical / NDT** (§2, §16).
- **TBD-2 → RESOLVED:** target transducer **3–4 MHz** (design with margin ~2–5 MHz).
- **TBD-3 → RESOLVED (conditional):** **unipolar preferred** (simplicity, DP3);
  **bipolar accepted iff** a **cheap symmetric ± rail** can be produced (see §8 T6).
- **TBD-4 → RESOLVED:** host link is **USB**, via an **on-board USB-C** connector;
  **USB bus-powered** (§10, §11).
- **TBD-5 → RESOLVED:** **A-mode** core; **M-mode** optional [S] (host-side, no extra
  HW); B-mode deferred [W].
- **TBD-7 → RESOLVED:** controller is the **RP2350** MCU (§10, DP4).

**Still open:**

| ID | Open decision | Working assumption in this draft |
|----|---|---|
| TBD-6 | Unit BOM cost | **drive as low as possible**; explore cheap options (no fixed cap yet) |
| ADEC | External ADC choice | **external high-speed ADC** on RP2350 PIO; at 3–4 MHz a **~20–30 MSps, 10–12-bit** part suffices (cheaper/smaller than 65 MSps) — pick the lowest-cost part that meets P3. See [`options.md`](options.md) §3 |
| RF-ACCESS | **Raw RF vs envelope?** | **Working assumption: raw RF** (F3). Key question: do we want users to access the **raw RF signal, not just the envelope?** Raw RF is what justifies the on-device **DSP** (S6), **coded excitation** + matched filtering (T4), and the external high-speed ADC. **Envelope-only would be simpler/cheaper but would not justify the DSP** and would collapse the external-ADC route (an internal 500 kSps ADC would do). **Decision pending** — if confirmed raw-RF, ADEC stands; if envelope-only, re-scope §0/§9 |
| TXRX-LINK | **TX & RX path linked by default?** | Single-element ⇒ TX and RX **share the element** through the T/R switch (F5) — **linked by default**. Question: keep them linked by default, and add a **jumper / solder-bridge** so users can **separate TX and RX** (e.g. for a dual-element / separate TX-RX transducer, F7)? Working assumption: **linked by default + a jumper to split** |

---

## 5. Functional requirements (F)

- **F1 [M]** The system shall drive a single piezo transducer with a configurable
  high-voltage pulse and receive the echo on the same or a paired element.
- **F2 [M]** The system shall drive the **provided single-element piezo (~3–4 MHz)**;
  the front-end may be tuned to that known element. Design margin ~2–5 MHz.
- **F2c [M]** The board shall offer **multiple transducer-connector footprints**:
  **SMA/coax**, a classical **2×1 2.54 mm header**, and a **uFL** (u.FL) connector
  (uFL for easy plug-in). Populating at least one is required; providing all footprints
  lets users pick per their transducer/lead.
- **F2a [S]** Suitable for **muscle-contraction monitoring** on superficial muscle
  (~1–4 cm depth) — the reference workshop application.
- **F3 [M]** The system shall acquire **raw RF** echo data (not envelope-only) for
  host-side processing.
- **F4 [M]** Acquisition parameters — pulse width, number of cycles, PRF, TGC curve,
  acquisition depth/length — shall be **host-configurable**.
- **F5 [S]** The system shall support a **T/R switch** so one element can transmit
  and receive. TX and RX are **linked by default** (shared element); a **jumper /
  solder-bridge** shall allow **splitting TX and RX** for a dual-element / separate
  TX-RX transducer (F7). See open item TXRX-LINK.
- **F6 [M]** The system shall provide a **receive gain stage** whose gain is
  **host-settable and changeable between firing lines** (a fixed gain per line, not
  swept within a line). **TGC (depth-variable gain within a line) is NOT required**
  (owner decision, 2026-09-18) — dropped for simplicity, since the reference
  application images at shallow, roughly fixed depth. Implementation options: a
  digipot/MDAC in an op-amp feedback path, a switched resistor bank, a PGA, or a VGA
  used at a static setting (see A3).
- **F7 [C]** The system should support a **dual-element** (separate TX/RX) mode via a
  second connector (cf. lit3rick).
- **F8 [S]** The system shall support **M-mode** (repeated A-lines over time,
  host-side; no extra hardware).
- **F9 [W]** Single-element B-mode (via an external scanning fixture) and
  multi-channel / array beamforming are deferred to a later version.
- **F10 [M]** The device shall be **hackable for workshop experimentation**: coded/
  encoded excitation (T4), adjustable acquisition parameters (F4), and open host
  processing (S2–S3) shall be exposed so attendees can try coded excitation, pulse
  compression, filtering, and M-mode of muscle contraction.
- **F11 [S]** **Autonomous RGB display:** the board shall carry at least one
  **addressable RGB LED** (e.g. WS2812/SK6812, RP2350 **PIO**-driven) so the badge
  gives **standalone visual feedback without a host** — status, and a demo that maps
  echo strength / muscle-contraction (M-mode) to colour. Reinforces the badge aspect.
- **F12 [S]** **Small OLED display** (common on workshop badges) — e.g. a 0.9″/1.3″
  **I²C SSD1306/SH1106** (128×32/128×64) — for standalone on-badge display (status, a
  live A-line / M-mode strip, simple menus) without a host. Shares the I²C bus (C5).

## 6. Performance requirements (P)

- **P1 [M]** Excitation frequency: **3–4 MHz** target (support ~2–5 MHz),
  transducer-dependent.
- **P2 [M]** Acquisition bandwidth (−3 dB): shall pass the transducer band up to
  **≥ 5 MHz** end-to-end (i.e., **not** bandwidth-capped below fc — the key
  differentiator from the MSP430 integrated route, see analysis §2).
- **P3 [M]** ADC sample rate: **≥ 4× fc** ⇒ **≥ 16 MSps** at 4 MHz; **target
  ≥ 20–30 MSps** (enough for 3–4 MHz RF; lets us pick a cheaper part than 65 MSps).
- **P4 [M]** ADC resolution: **≥ 10-bit** (≥ 9-bit gives ~50 dB SNR per the
  literature; 12-bit [S] for dynamic range).
- **P5 [S]** System SNR: **≥ 50 dB** on a reference reflector/phantom.
- **P6 [S]** Programmable **PRF** at least **100 Hz–10 kHz**.
- **P7 [S]** Acquisition depth: capture **≥ 120 µs** per line (≈ 9 cm at 1540 m/s),
  host-extendable.
- **P8 [C]** Total settable gain range **≥ 40 dB** (fixed + per-line-settable stage;
  no TGC — see F6/A3).

## 7. Analog front-end / signal chain (A)

- **A1 [M]** RX chain: transducer → T/R protection → (low-noise amp, A3a) →
  settable-gain stage (A3) → anti-alias filter → ADC.
- **A2 [M]** RX input protection shall survive the transmit pulse (T/R switch or
  clamp, e.g., MD0100/MD0101-class).
- **A3 [S]** The gain stage shall be **digitally settable between lines** (F6). Since
  **TGC is not required**, a smooth fast control is unnecessary: a **digital
  potentiometer / MDAC in an op-amp feedback path**, a **switched resistor bank**, an
  integrated **PGA**, or a **VGA held at a static setting** all satisfy it. (A VGA such
  as AD8331/AD8338 remains acceptable but is no longer required — gain lives in a
  resistor ratio, so a digitally-controlled resistor is the natural cheap primitive; a
  DAC voltage sets gain only in a true VGA/multiplier.)
- **A3a [C]** A **fixed low-noise LNA** as the first RX stage (ahead of the settable
  gain) — sets the noise floor for weak echoes (esp. with a low-voltage pulser).
  Optional; add if op-amp-input noise limits SNR.
- **A4 [S]** Anti-alias filtering matched to the ADC rate and transducer band.
- **A5 [M]** **Single-supply input conditioning.** The ADC is single-supply
  (0 → VREF ≈ 3.3 V, no negative input), so the 0-centred RF (≈ ±2 V raw) shall be
  **AC-coupled, biased to mid-rail (VREF/2 ≈ 1.65 V)**, and **scaled so the largest echo
  of interest fits ~2.6–2.8 Vpp** with rail headroom — never fed bipolar. A **mid-rail
  bias buffer** provides the reference; an **overrange clamp** at the ADC/op-amp node keeps
  pins within 0–VREF. Prefer **single-ended** (this ADC's differential range is limited).
  Per-line gain (A3/F6) doubles as the fit-to-ADC / auto-range control. See
  [`design/designA/README.md`](design/designA/README.md) §5a.

## 8. Transmit / pulser (T)

- **T1 [M]** Generate a configurable **unipolar** HV pulse for ~3–4 MHz excitation.
- **T2 [M]** Pulse amplitude: unipolar, **configurable**, baseline **~+20–30 V**,
  capability up to **~+50 V** if cheap to do; single minimal HV rail (DP2/DP3).
- **T3 [M]** Simplest unipolar transmit: **single MOSFET + gate driver** driving the
  transducer, plus a T/R switch/clamp to protect RX (MD0100/MMBD-class). The HV rail
  may be as simple as the **USB +5 V rail directly** (no boost IC — cheapest, low
  amplitude) or a **small boost** for a stronger pulse; either way the HV node is on a
  header (T7) so users can **swap in external HV**. Choose per `options.md` (U0/U1).
- **T4 [M]** **Programmable / arbitrary excitation** — the pulser gate is driven by
  the **RP2350 PIO**, so workshop users can generate multi-cycle bursts, swept-
  frequency (chirp), pulse-position and on-off-keyed (OOK) **coded excitation** and
  experiment with pulse compression. This is a core workshop feature.
- **T4a [M]** **Jumper-selectable pulser-drive source (two-MCU builds, e.g. DesignA):**
  the pulser MOSFET gate shall be drivable from **either** the controller
  (**RP2354/RP2350 PIO**) **or** the capture MCU (**PIC32 HS-PWM**), chosen by a
  **jumper / solder-bridge** (3-pin: gate = centre, the two sources = ends). This lets
  TX sequencing be owned by whichever suits — **PIC32 HS-PWM** for tight on-chip TX↔ADC
  sync, or **RP2354 PIO** for coded excitation from the host side. **Only one source
  drives the gate at a time** (the other pin held Hi-Z/input); the gate driver, if any,
  sits after the jumper. See [`design/designA/README.md`](design/designA/README.md) §4.
- **T5 [note]** True **bipolar phase codes** (e.g., ±1 Barker) need a *bipolar*
  pulser; the unipolar baseline supports frequency/pulse-train/OOK coding only.
- **T6 [S]** **Bipolar option (conditional):** bipolar transmit is accepted **iff** a
  **cheap, simple symmetric ± rail** can be generated. **Cheapest answer: a
  +5→−5V charge pump** (e.g. TPS60403 / ICL7660 / LM2776, ~$0.4) gives a symmetric
  **±5V** rail — low amplitude but enough to demo **true ±1 phase-coded excitation**
  (options.md B0). For higher voltage, explore an inverting/dual-output / SEPIC-Ćuk
  converter or two small boosts (one inverted). If a viable ± rail is used,
  a bipolar pulser (e.g. MD1210/MD1213 + TC6320, as in pic0rick — DP5) becomes
  viable and **unlocks true ±1 phase-coded excitation** for the workshop (synergy
  with T4). Otherwise, stay unipolar (T1–T3).
- **T7 [S]** **HV rail(s) on a header (external-HV option):** bring the HV rail(s) to
  an accessible header with a **jumper / solder-bridge** to isolate the on-board HV
  supply, so users can **feed external HV** or replace the on-board generator entirely
  (e.g. via an extension board, C5). Expose the relevant control PIO(s) too.

## 9. Digitization & data (D)

- **D1 [M]** Digitize raw RF at the P3/P4 rate/resolution using an **external
  high-speed ADC** (ADEC) — the RP2350 internal 500 kSps ADC is insufficient (§0).
- **D2 [M]** Buffer at least **one full acquisition line** in **RP2350 RAM** (via
  PIO/DMA FIFO), decoupling ADC bursts from the USB transfer.
- **D3 [S]** Sustain streaming of consecutive lines at the working PRF over the host
  link without loss (or buffer + burst).
- **D4 [C]** On-board persistent storage (SD) for untethered raw capture (cf. IUP).

## 10. Control, connectivity & host (C)

- **C1 [M]** The controller shall be the **Raspberry Pi RP2350** (DP4), with
  RP2350B preferred for the extra GPIO (parallel ADC bus + control lines).
- **C1a [M]** **Precise pulse-sequence timing:** the controller shall generate the
  TX pulse-sequence logic with **cycle-accurate, ~ns-resolution deterministic timing**
  (via **PIO**), enough to define pulse width, count, delays, and coded/chirp
  sequences (T4).
- **C1b [M]** **Fast, steady acquisition:** the controller shall capture the external
  ADC (ADEC) as a **continuous, gap-free** stream at the full P3 sample rate into RAM
  (**PIO + DMA**), sustaining one full acquisition line (D2) without dropped samples.
- **C1c [M]** **Acquisition tightly coupled to TX (hardware trigger):** the ADC
  acquisition start shall be triggered **in hardware, off the same timebase as the pulser
  first edge** — not by software/interrupt — for phase-locked, low-jitter capture with a
  programmable pre-delay (blank TX artifact / set near-field start). On the PIC32A route
  this is native: the **HS-PWM that drives the pulser also emits the ADC trigger** (same
  counter), with **PTG** for coded-burst sequences (DesignA §5b) — which favours the
  **PIC-owns-TX** JP1 setting (T4a). On the RP2350-only route, the PIO pulse-start shall
  hardware-trigger the ADC likewise.
- **C2 [M]** Host interface: **USB** on the RP2350's native USB, via an **on-board
  USB connector (USB-C preferred)**, presenting a documented command/data protocol.
- **C3 [M]** A **Python** host API/reference client shall configure acquisitions and
  read back raw data.
- **C4 [C]** Wireless (BLE/Wi-Fi) host link for untethered use — only if it does not
  compromise DP1–DP3.
- **C5 [S]** **Standardised extension header:** expose the RP2350 on a **Raspberry Pi
  2×20 (40-pin) header** pinout — bringing out **UART, I²C, SPI**, GPIO/spare PIO,
  and power/ground — so extensions communicate in a **standard, HAT-style** way (as
  the owner's un0rick did — DP5). This carries the OLED (F12, I²C) and enables add-on
  boards (channel mux, storage, alternative front-ends, external HV — see T7). Document
  the pinout; note where it deviates from the RPi map (RP2350 ≠ RP1).

## 11. Power (PW)

- **PW1 [M]** **USB bus-powered** from the on-board USB-C connector (5 V); no
  separate power input required for baseline operation.
- **PW2 [S]** Total power within the USB budget and **≤ ~2 W** tethered.
- **PW3 [M]** On-board generation of the rails the chain needs (e.g., ADC/AFE
  supplies and the HV pulser rail) from USB 5 V, kept minimal per DP2/DP3.
- **PW4 [C]** Battery option for untethered use if C4 is pursued.

## 12. Mechanical / form factor (M)

- **M1 [M]** **Single small PCB** in a **conference-badge form factor** — flat,
  badge-sized, with a **lanyard hole** and room for **silkscreen artwork** and the
  **OSHWA certification mark + UID** (O3) — fabricable by a standard low-cost house
  (e.g., JLCPCB) from the published files (DP1).
- **M2 [M]** On-board **USB-C** connector (host + power). Transducer footprints per
  F2c: SMA/coax **+** 2×1 2.54 mm header **+** uFL.
- **M3 [S]** Minimise board area and component height so it wears as a badge.
- **M4 [C]** A handheld/on-body probe enclosure is out of scope for v1.0 (the piezo is
  applied by hand during the workshop).
- **M5 [S]** **User-friendly silkscreen (layout, not BOM):** label the functional
  blocks (pulser / HV / T-R / VGA-TGC / ADC / RP2350), name connectors and header
  pins, and add brief function hints — the board should teach itself for the workshop.
- **M6 [S]** **Test points** on key logic and analog nodes (e.g. TX gate, HV rail(s),
  AFE output, ADC clock/data, PIO lines) so attendees can probe/learn and debug.
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

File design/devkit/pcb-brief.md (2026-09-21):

# minus DesignA-DK — PCB design brief

**Single-channel pulse-echo ultrasound development / derisking board.**
Contact: kelu124 (Luc J). Prior art: [kelu124/pic32arick](https://github.com/kelu124/pic32arick).
Fuller rationale + test plan: [`README.md`](README.md) in this folder.
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

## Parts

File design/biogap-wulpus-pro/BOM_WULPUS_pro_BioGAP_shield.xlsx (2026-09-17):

Comment | Quantity | Designator | Description
GJM1555C1H1R5BB01D | 1 | C1 | GJM1555C1H1R5BB01D
C0402C104K4RACTU | 17 | C2, C15, C16, C17, C19, C25, C27, C29, C46, C47, C48, C68, C69, C70, C71, C75, C76 | C0402C104K4RACTU
GRM033R71A103KA01D | 2 | C3, C6 | GRM033R71A103KA01D
GRM1555C1H102JA01D | 8 | C4, C7, C9, C38, C40, C41, C51, C77 | GRM1555C1H102JA01D, Chip Multilayer Ceramic Capacitors for General Purpose, 0402, 1000pF, C0G, 30ppm/°C, 5%, 50V
04025C332JAT2A | 1 | C5 | 04025C332JAT2A
C1005X7S1A225K050BC | 14 | C8, C12, C13, C18, C24, C26, C28, C43, C44, C45, C72, C73, C74, C80 | C1005X7S1A225K050BC
04025A101FAT2A | 2 | C11, C23 | 04025A101FAT2A
GRM188R60J476ME01D | 3 | C14, C39, C42 | GRM188R60J476ME01D
GRM1555C1H100JA01D | 2 | C20, C21 | GRM1555C1H100JA01D
GRM188R61H225ME11D | 7 | C22, C56, C57, C58, C60, C61, C63 | GRM188R61H225ME11D
GRM188R61H225ME11 | 8 | C30, C31, C32, C33, C34, C35, C78, C79 | GRM188R61H225ME11
GRM155R71H473ME14D | 2 | C36, C37 | GRM155R71H473ME14D
GJM1555C1H120GB01D | 6 | C49, C50, C52, C53, C54, C55 | Multi-Layer Ceramic Capacitor 12pF C0G ±2% 0402 Paper T/R
GCM21BR71H105KA03L | 1 | C59 | GCM21BR71H105KA03L
GRM155C71H104KE19D | 1 | C62 | GRM155C71H104KE19D
GRM155Z71A105KE01D | 4 | C64, C65, C66, C67 | GRM155Z71A105KE01D
BAV99T-7-F | 1 | D1 | DIODE ARRAY GP 85V 75MA SOT523
APHD1608LZGCK | 1 | D2 | LED GREEN CLEAR 1608 SMD
ZHCS400QTA | 1 | D3 | Diode Schottky 40V 1A Automotive 2-Pin SOD-323 T/R
BLM18SP101SN1D | 2 | FB1, FB2 | BLM18SP101SN1D Ferrite Bead, 100 Ohm, 3.7A, 0603 Rohs Compliant: Yes
BLM18SP101SH1D | 2 | FB3, FB4 | BLM18SP101SH1D Ferrite Beads Multi-Layer 100Ohm 25% 100MHz 3.7A 0.022Ohm DCR 0603 Automotive T/R
DF40C-40DS-0.4V(51) | 2 | J1, J2 | CONN RCPT 40POS SMD GOLD
DF52-16S-0.8H(21) | 2 | J4, J6 | No Description Available
U.FL-R-SMT-1(10) | 3 | J10, J11, J15 | CONN U.FL RCPT STR 50 OHM SMD
DF40HC(3.0)-50DS-0.4V(51) | 1 | J12 | 50 Position 0.4mm Pitch Dual Row Vertical Surface Mount (SMT) Pin Socket, 3.0mm Stacking Height
742792040 | 2 | L1, L2 | SMD EMI Suppression Ferrite Bead WE-CBF, Z = 600 Ohm
LQH3NPZ100MMEL | 2 | L3, L4 | Wire Wound Ferrite Inductor for Power Lines For Automotive 10μH ±20% 0.228Ω 1280mA 1212
NX7002BKMBYL | 1 | Q1 | MOSFET (N-Channel)
CRCW04021K30JNED | 1 | R1 | CRCW04021K30JNED
ERJ-2RKF2001X | 2 | R2, R3 | ERJ-2RKF2001X
CRCW04021R00FKEDC | 1 | R4 | CRCW04021R00FKEDC
MCS04020C2701FE000 | 1 | R5 | MCS04020C2701FE000
CRCW04020000Z0ED | 3 | R8, R18, R46 | CRCW04020000Z0ED
RMCF0201JT47K0 | 1 | R9 | RMCF0201JT47K0
CRCW040210K0JNED | 8 | R10, R11, R12, R14, R16, R22, R43, R44 | CRCW040210K0JNED
CRCW040251R0JNED | 1 | R13 | CRCW040251R0JNED
ERJ-3GEY0R00V | 1 | R15 | ERJ-3GEY0R00V
CRCW0402402RFKEDC | 2 | R21, R34 | CRCW0402402RFKEDC
ERJ-PA3J302V | 2 | R23, R24 | Resistor, ERJ-PA3J302V
RC1005F394CS | 2 | R26, R29 | RC1005F394CS
ERJ-2RKF1003X | 2 | R27, R28 | ERJ-2RKF1003X
CRCW04021M00FKED | 2 | R31, R32 | RES Thick Film, 1MΩ, 1%, 0.063W, 100ppm/°C, 0402
RC0402JR-0722RL | 3 | R33, R35, R38 | RC0402JR-0722RL, [NoValue]
CPF0402B324RE1 | 1 | R36
CRCW040247K0FKED | 1 | R37 | RES Thick Film, 47kΩ, 1%, 0.063W, 100ppm/°C, 0402
ERJ-2RKF1004X | 2 | R39, R42 | ERJ-2RKF1004X
ERJ-2RKF4322X | 1 | R40 | ERJ-2RKF4322X
ERJ-2RKF4122X | 1 | R41 | ERJ-2RKF4122X
AD8338ACPZ-R7 | 1 | U1 | IC OPAMP VGA 1 CIRCUIT 16LFCSP
OPA836IDBVT | 2 | U2, U10 | Very Low Power, Rail to Rail Out, Negative Rail In, VFB Operational Amplifier, 2.5 to 5.5 V, -40 to 125 degC, 6-pin SOT23 (DBV6), Green (RoHS & no Sb/Br)
TPL0501-100RSER | 1 | U3 | 256-Tap, 100 k, Single Channel Potentiometer with SPI Interface, -40 to 125 degC, 8-pin QFN (RSE8), Green (RoHS & no Sb/Br)
TS5A3159AYZPR | 2 | U4, U7 | Analogue Switch ICs SPDT ANALOG SWITCH
LTC5507ES6#TRMPBF | 1 | U5 | IC RF DETECT 100KHZ-1GHZ TSOT23
TPS22916CYFPR | 4 | U6, U8, U12, U16 | TPS22916 5.5-V, 2-A Ultra-Low Leakage Load Switch
IXDD604D2TR | 1 | U9 | Integrated Circuit
HV2707T-C/R8X | 1 | U11 | 16-CH 200V No Hv Bias Switch (SPST), 2 Bleed Resistor 48 LQFP 7X7X1.4MM T/r Rohs Compliant: Yes
MD0100 | 1 | U13
MSP430FR5043IRGCT | 1 | U14 | No Description Available
LT3463EDD#PBF | 1 | U15 | Dual Micropower DC/DC Converters with Schottky Diodes, 2.4 to 15 V Vin, 10-pin SON (DD-10), -40 to 85 degC, Pb-Free
SN74AVC4T774RSVR | 2 | U17, U18 | Voltage Level Translator Bidirectional 1 Circuit 4 Channel 380Mbps 16-UQFN _2.6x1.8_
FY0800018 | 1 | X2 | Crystal 8MHz ±30ppm (Tol) ±30ppm (Stability) 18pF FUND 100Ohm 4-Pin SMD T/R
AWSCR-8.00CV-T | 1 | Y1 | No Description Available
ABS05-32.768KHZ-9-T | 1 | Y2 | CRYSTAL 32.7680KHZ 9PF SMD

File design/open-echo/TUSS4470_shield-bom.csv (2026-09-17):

Designator | Footprint | Quantity | Value | LCSC Part #
C1 | 0603 | 1 | C15nF | C1596
C10 | 0603 | 1 | 8.2nF | C1322360
C2 | 0603 | 1 | C106nF | C14663
C3 | 0603 | 1 | C3.2nF | C1613
C4 | 0603 | 1 | C21.2nF | C1602
C5 | 0603 | 1 | 40V, 330pF | C1664
C6 | 1206 | 1 | 40V, 2µF | C50254
C7 | 0603 | 1 | 50V, 100nF | C14663
C8 | 0603 | 1 | 10nF | C57112
C9 | 0603 | 1 | 1nF | C1588
D1 | D_SMA | 1 | 1N4001 | C727079
D2 | 0805 | 1 | LED_PWR | C84256
D3 | 0805 | 1 | LED_VIN | C84256
D4 | 0805 | 1 | LED_XT30 | C84256
J1 | AMASS_XT30PW-M_1x02_P2.50mm_Horizontal | 1 | VIN | C431092
J4 | PinHeader_1x03_P2.54mm_Vertical | 1 | VCC SELECT | C49257
JP1, JP2 | PinHeader_1x02_P2.54mm_Vertical | 2 | 40kHz | C2905434
JP3, JP4 | PinHeader_1x02_P2.54mm_Vertical | 2 | 200kHz | C2905434
JP5, JP6 | PinHeader_1x02_P2.54mm_Vertical | 2 | CUSTOM kHz | C2905434
R1 | 1206 | 1 | R10 | C17903
R2 | 1206 | 1 | R200 | C18002
R3 | 0603 | 1 | R330 | C23138
R4 | 0603 | 1 | R1k | C14676
R5 | 0603 | 1 | R2.2k | C4190
SW1 | SW_Push_1P1T_NO_CK_KSC7xxJ | 1 | RST | C318884
U1 | QFN-20-1EP_4x4mm_P0.5mm_EP2.5x2.5mm_ThermalVias | 1 | TUSS4470TRTJR | C1855776

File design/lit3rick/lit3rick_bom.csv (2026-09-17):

Reference Designator | Description | Manufacturer | Manufacturer Part Number | Suppliers | Package | Quantity | Capacitance | Voltage | Is Generic | Symbol Type | Nobom | Mouser Part Number | Digikey Part Number | Verified Pad Assignment | Temperature Range Low | Verified Attributes | Verified Pin Names | Digikey Description | Verified Geometry | Mfg Package Ident | Temperature Range High | Centroid Not Specified | Ipc Land Pattern Name | Imported | Component Link 1 Url | Component Link 1 Description | If Max | Vr Max | Vault Guid | Vbr Min | Footprint Variant Name 2 | Footprint Variant Name 1 | Footprint Variant Name 0 | Vf Max | Ciiva Ids | Package Version | Release Date | Vault Revision | Trr Max | Ir Max | Component Link 3 Description | Import Ts | Green | Package Description | Imported From | Configuration | Conn 0 Type | Conn 1 Type | Mounting Technology | Conn 2 Type | Component Link 3 Url | Resistance | Resistor | Inductance | Footprint Parameters 0 | Operating Force | Termination Style | Operating Temperature | Actuator Orientation
C1 C10 C101 C102 C103 C16 C18 C2 C21 C29 C30 C32 C34 C58 C59 C60 C7 C75 C77 C78 C79 C8 C80 C83 C84 C85 C87 C88 C89 C91 C92 C97 C99 | Generic Capacitor (Non-Polarized) (1e-07F) | Generic | Capacitor (1e-07F) |  | 0402 (1005 metric) | 33 | 1e-07F | 10V | true | Capacitor
C100 C90 C93 C96 C98 | Generic Capacitor (Non-Polarized) (1e-09F) | Generic | Capacitor (1e-09F) |  | 0402 (1005 metric) | 5 | 1e-09F | 10V | true | Capacitor
C104 | Generic Capacitor (Non-Polarized) (1.8e-08F) | Generic | Capacitor (1.8e-08F) |  | 0402 (1005 metric) | 1 | 1.8e-08F | 10V | true | Capacitor
C105 C81 | Generic Capacitor (Non-Polarized) (2.2e-11F) | Generic | Capacitor (2.2e-11F) |  | 0402 (1005 metric) | 2 | 2.2e-11F | 10V | true | Capacitor
C11 C3 | Generic Capacitor (Non-Polarized) (1e-05F) | Generic | Capacitor (1e-05F) |  | 0603 (1608 metric) | 2 | 1e-05F | 10V | true | Capacitor
C12 C13 C14 C15 C19 C31 C33 C35 C76 C82 C86 | Generic Capacitor (Non-Polarized) (1e-06F) | Generic | Capacitor (1e-06F) |  | 0402 (1005 metric) | 11 | 1e-06F | 10V | true | Capacitor
C17 C4 C5 C6 C9 | Generic Capacitor (Non-Polarized) (1e-08F) | Generic | Capacitor (1e-08F) |  | 0402 (1005 metric) | 5 | 1e-08F | 10V | true | Capacitor
C20 | Generic Capacitor (Non-Polarized) (1e-07F) | Generic | Capacitor (1e-07F) |  | 0402 (1005 metric) | 0 | 1e-07F | 10V | true | Capacitor | true
C41 C40 | Generic Capacitor (Non-Polarized) (1e-07F) | Generic | Capacitor (1e-07F) |  | 0805 (2012 metric) | 2 | 1e-07F | 100V | true | Capacitor
C42 C43 | Generic Capacitor (Non-Polarized) (1e-06F) | Generic | Capacitor (1e-06F) |  | 1206 (3216 metric) | 2 | 1e-06F | 100V | true | Capacitor
D1 D2 D3 D4 | LED COOL WHITE DIFFUSED 0603 SMD | Broadcom | HSMW-C191 |  | 0603 | 4 |  |  |  |  |  | 630-HSMW-C191 | 516-2236-1-ND | true | -40°C | true | true | LED COOL WHITE DIFFUSED 0603 SMD | true | LED_0630 | +85°C | No
D5 | Red, Green, Blue (RGB) 622nm Red, 530nm Green, 470nm Blue LED Indication - Discrete 1.9V Red, 3V Green, 3V Blue 4-PLCC | Cree Inc. | CLVBA-FKA-CAEDH8BBB7A363 |  | PLCC4 | 1 |  |  |  |  |  | 941-VBAFKACAEDH8B7A3 | CLVBA-FKA-CAEDH8BBB7A363CT-ND | true | -40°C | true | true | LED RGB DIFFUSED 4PLCC SMD | true |  | +100°C | No
D6 | DIODE SCHOTTKY 20V 500MA 0603 | Comchip Technology | CDBU0520 |  | 0603 | 1 |  |  |  |  |  |  |  |  |  |  |  |  |  |  |  |  | CAPC16080X45
D7 D8 D9 | INF-D_A1K2C3-3 | Infineon | MMBD7000 |  | SOT23 | 3 |  |  |  |  |  |  |  | true |  | true | true |  | true |  |  |  |  | yes | http://www.infineon.com/ | Manufacturer URL | 200Â mA | 100Â V | 86C1F83D-EC59-44F1-9867-E9D6C11F6D6A | 100Â V | Level A | Level B | Level C | 1.25Â V | 21174180 | Apr-08 | 1409237748 | CDAFAE1B-41C8-4BAF-B02C-B3E8A5C9B73F | 4Â ns | 500Â nA | Package Specification | 1521862220 | true | 3-Pin Small Outline Transistor Package, 1.3 x 2.9 mm Body, 0.95 mm Pitch | vault | Dual | passive | passive | Surface Mount | passive | http://www.infineon.com/dgdl/SOT23-Package_Overview.pdf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
J1 | 40-Pin GPIO Through Holes for Raspberry Pi | N/A | 40-Pin Raspberry Pi B+ GPIO Through Holes |  | 40-Pin 2.54mm Pitch Through Holes | 1
J5 J6 | No description | AMPHENOL | 132357-11 |  | CONN_SMA_9MM52_7M92 | 2 |  |  |  |  |  |  |  |  |  |  |  |  |  |  |  | No |  |  |  |  |  |  |  |  |  |  |  |  |  |  |  |  |  |  |  |  |  |  |  |  |  |  |  |  |  | 50
L10 L12 L13 L14 L8 L9 | Generic Inductor (1e-07H) | Generic | Inductor (1e-07H) |  | 0805 (2012 metric) | 6 |  |  | true | Inductor |  |  |  |  |  |  |  |  |  |  |  |  |  |  |  |  |  |  |  |  |  |  |  |  |  |  |  |  |  |  |  |  |  |  |  |  |  |  |  |  |  |  | 75R @100MHz | 1e-07H
R1 R2 R3 R4 | Generic Resistor (649) | Generic | Resistor (649) |  | 0603 (1608 metric) | 4 |  |  | true | Resistor |  |  |  |  |  |  |  |  |  |  |  |  |  |  |  |  |  |  |  |  |  |  |  |  |  |  |  |  |  |  |  |  |  |  |  |  |  |  |  |  |  | 649
R10 R5 R7 R8 R9 | Generic Resistor (100) | Generic | Resistor (100) |  | 0402 (1005 metric) | 5 |  |  | true | Resistor |  |  |  |  |  |  |  |  |  |  |  |  |  |  |  |  |  |  |  |  |  |  |  |  |  |  |  |  |  |  |  |  |  |  |  |  |  |  |  |  |  | 100
R15 R16 R17 R18 R36 R41 R42 R44 R45 R6 R37 | Generic Resistor (10000) | Generic | Resistor (10000) |  | 0402 (1005 metric) | 11 |  |  | true | Resistor |  |  |  |  |  |  |  |  |  |  |  |  |  |  |  |  |  |  |  |  |  |  |  |  |  |  |  |  |  |  |  |  |  |  |  |  |  |  |  |  |  | 10000
R26 R27 | Generic Resistor (0) | Generic | Resistor (0) |  | 0603 (1608 metric) | 2 |  |  | true | Resistor |  |  |  |  |  |  |  |  |  |  |  |  |  |  |  |  |  |  |  |  |  |  |  |  |  |  |  |  |  |  |  |  |  |  |  |  |  |  |  |  |  | 0
R38 R39 | Generic Resistor (18) | Generic | Resistor (18) |  | 0402 (1005 metric) | 2 |  |  | true | Resistor |  |  |  |  |  |  |  |  |  |  |  |  |  |  |  |  |  |  |  |  |  |  |  |  |  |  |  |  |  |  |  |  |  |  |  |  |  |  |  |  |  | 18
R40 | Generic Resistor (0) | Generic | Resistor (0) |  | 0402 (1005 metric) | 1 |  |  | true | Resistor |  |  |  |  |  |  |  |  |  |  |  |  |  |  |  |  |  |  |  |  |  |  |  |  |  |  |  |  |  |  |  |  |  |  |  |  |  |  |  |  |  | 0
R43 | Generic Resistor (1000) | Generic | Resistor (1000) |  | 0402 (1005 metric) | 1 |  |  | true | Resistor |  |  |  |  |  |  |  |  |  |  |  |  |  |  |  |  |  |  |  |  |  |  |  |  |  |  |  |  |  |  |  |  |  |  |  |  |  |  |  |  |  | 1000
R46 | Generic Resistor (280) | Generic | Resistor (280) |  | 0402 (1005 metric) | 1 |  |  | true | Resistor |  |  |  |  |  |  |  |  |  |  |  |  |  |  |  |  |  |  |  |  |  |  |  |  |  |  |  |  |  |  |  |  |  |  |  |  |  |  |  |  |  | 280
S1 S2 | No description | Panasonic Electronic Components | EVQ-P9P02M |  |  | 2 |  |  |  |  |  |  |  |  |  |  |  |  |  |  |  | No | DFN400X400X80-14 |  |  |  |  |  |  |  |  |  |  |  |  |  |  |  |  |  |  |  |  |  | PartsBot |  |  |  |  |  |  |  |  |  | {"fp_type":"DFN","params":{"N":{"nom":"14","long name":"Number of leads","min":null,"max":null,"short name":"N","type":"count"},"A":{"nom":false,"long name":"Height","min":false,"max":800000,"short name":"A","type":"measurement"},"A1":{"nom":0,"long name":"Package clearance","min":false,"max":false,"short name":"A1","type":"measurement"},"A2":{"nom":false,"long name":"Package height","min":false,"max":800000,"short name":"A2","type":"measurement"},"D":{"nom":false,"long name":"Package length","min":3900000,"max":4100000,"short name":"D","type":"measurement"},"E":{"nom":false,"long name":"Package width","min":3900000,"max":4100000,"short name":"E","type":"measurement"},"B":{"nom":false,"long name":"Lead width","min":200000,"max":300000,"short name":"B","type":"measurement"},"C":{"nom":100000,"long name":"Lead thickness","min":null,"max":null,"short name":"C","type":"measurement"},"L":{"nom":false,"long name":"Lead foot length","min":300000,"max":500000,"short name":"L","type":"measurement"},"e":{"nom":500000,"long name":"Lead pitch","min":null,"max":null,"short name":"e","type":"measurement"},"HT":{"default":"No","long name":"Thermal pad","type":"multichoiceparent","short name":"HT","children":[]},"offset x":{"nom":0,"long name":"X Center offset","min":null,"max":null,"short name":"offset x","type":"measurement"},"offset y":{"nom":0,"long name":"Y Center offset","min":null,"max":null,"short name":"offset y","type":"measurement"},"LS":{"default":"Rounded rectangle","long name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 | 500gf | J Lead | -40°C ~ 85°C | Top Actuated
U1 | FPGA | Lattice | iCE40UP5K-SG48I |  | QFN48 | 1 |  |  |  |  |  |  |  |  |  |  |  |  |  |  |  |  | QFN50P700X700X90-48 |  |  |  |  |  |  |  |  |  |  |  |  |  |  |  |  |  |  |  |  |  |  |  |  | I/O |  | I/O |  |  |  |  | {"fp_type":"QFN","params":{"N1":{"nom":12,"long name":"Leads on long side","min":null,"max":null,"short name":"N1","type":"count"},"N2":{"nom":12,"long name":"Leads on wide side","min":null,"max":null,"short name":"N2","type":"count"},"A":{"nom":false,"long name":"Height","min":800000,"max":1000000,"short name":"A","type":"measurement"},"A1":{"nom":false,"long name":"Package clearance","min":0,"max":50000,"short name":"A1","type":"measurement"},"A2":{"nom":false,"long name":"Package height","min":800000,"max":false,"short name":"A2","type":"measurement"},"D":{"nom":7000000,"long name":"Package length","min":false,"max":false,"short name":"D","type":"measurement"},"E":{"nom":7000000,"long name":"Package width","min":false,"max":false,"short name":"E","type":"measurement"},"B":{"nom":200000,"long name":"Lead width","min":150000,"max":240000,"short name":"B","type":"measurement"},"C":{"nom":20000,"long name":"Lead thickness","min":null,"max":null,"short name":"C","type":"measurement"},"L":{"nom":400000,"long name":"Lead foot length","min":350000,"max":550000,"short name":"L","type":"measurement"},"e":{"nom":500000,"long name":"Lead pitch","min":null,"max":null,"short name":"e","type":"measurement"},"HT":{"default":"Yes","long name":"Thermal pad","type":"multichoiceparent","short name":"HT","children":["D2","E2","PC"]},"offset x":{"nom":0,"long name":"X Center offset","min":null,"max":null,"short name":"offset x","type":"measurement"},"offset y":{"nom":0,"long name":"Y Center o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
U10 | High-Speed ±100V 2.5A Two-or-Three-Level Ultrasound Pulsers | Microchip | HV7361GA-G |  | CABGA222 | 1 |  |  |  |  |  | 579-HV7361GA-G | HV7361GA-G-ND | true | -20°C | true | true | IC ULTRASOUND DRIVER 22CABGA | true | JY | +85°C | No | BGA126N50P9X14_700X500X70 |  |  |  |  |  |  |  |  |  |  |  |  |  |  |  |  |  |  |  |  |  |  |  | power | input |  | input
U2 | Buffer, Non-Inverting 2 Element 1 Bit per Element Push-Pull Output SOT-23-6 | Texas Instruments | SN74LVC2G17DBVR |  | SOT-23-6 | 0 |  |  |  |  | true | 595-SN74LVC2G17DBVR | 296-13012-1-ND | true | -40°C | true | true | IC BUFF DL SCHMIT TRIG SOT23-6 | true | DBV (R-PDSO-G6) | +125°C | No
U261 | 12-Bit, 20 MSPS/40 MSPS/65 MSPS/80 MSPS bigger holes | Analog | AD9629BCPZ-65 |  | CP-32-4 | 1
U281 U282 | 2x1 Male Header |  | Male Header - 2 pin |  | pitch = 2.54mm | 2
U284 |  | ANALOG DEVICES | AD8331ARQZ | Digi-Key AD8331ARQZ-ND/Newark 59K6617 | SOP64P600X165-20N | 1 |  |  |  |  |  |  |  |  |  |  |  |  |  |  |  |  |  |  |  |  |  |  |  |  |  |  |  |  |  |  |  |  |  |  |  |  |  |  | Eagle
U3 | High-Accuracy, Low-Power, Digital Temperature Sensor With SMBus and Two-Wire Serial Interface in SOT563 | Texas Instruments | TMP112AIDRLR |  | SOT6 | 1 |  |  |  |  |  | 595-TMP112AIDRLR | 296-38578-1-ND | true | -40°C | true | true | SENSOR TEMP I2C/SMBUS 6SOT | true |  | +125°C | No |  |  |  |  |  |  |  |  |  |  |  |  |  |  |  |  |  |  |  |  |  |  |  |  | input | power |  | output
U5 | NOR MEMORy 1M | WINBOND | W25X10CLSNIG |  | SOIC-SA8 | 1
U6 | TI-TLV707XXX-DQN4-480X480TP | Texas Instruments | TLV70718PDQNR |  | DQN0004A | 1 |  |  |  |  |  |  |  | false |  | false | false |  | false |  |  |  |  | yes | http://www.ti.com/ | Manufacturer URL |  |  | 3F66D4EA-FB2E-40E5-83D0-DABEA24CEAAC |  |  |  |  |  |  | 4210367/D |  |  |  |  |  | 1521171487 |  | 4-Pin Plastic Small Outline, Body 1 x 1 mm, Pitch 0.65 mm | vault |  |  |  | Surface Mount
U7 | CON-DAC-MCP4822-8 | Microchip | MCP4812-E/MS |  | MSOP-MS8 | 1 |  |  |  |  |  |  |  | true |  | true | true |  | true |  |  |  |  | yes | http://www.microchip.com/ | Manufacturer URL |  |  | 7B7BD816-BB23-4DA5-958B-16E84D640D03 |  | Level A | Level B | Level C |  | 2294755 | revBB, Aug-2009 | 1331963107 | BEE79A88-C9FA-48DF-8DD2-D9B6453D4ACA |  |  | Package Specification | 1521847306 |  | 8-Lead Plastic Micro Small Outline Package (MS) [MSOP] | vault |  | power | input |  | input | http://www.microchip.com/stellent/groups/techpub_sg/documents/packagingspec/en012702.pdf
U8 | 1v2 LDO | TI | TLV70712PDQNR |  | DQN4-480X480TP | 1
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

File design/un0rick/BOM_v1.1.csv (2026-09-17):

Reference Designator | Description | Manufacturer | Manufacturer Part Number | Suppliers | Package | Quantity | Symbol Type | Capacitance | Voltage | Tolerance | Is Generic | Dielectric | Mouser Part Number | Digikey Description | Verified Pad Assignment | Temperature Range Low | Verified Attributes | Digikey Part Number | Verified Geometry | Ipc Land Pattern Name | Verified Pin Names | Temperature Range High | Centroid Not Specified | Imported From | Color | Category A1D76Cdd91F27A10 | Category 848D4987B4D35F4A | Category Ab56665C9B747091 | Category 0Dd3C0D93D8Cd614 | Resistance | Mounting Type | Is Female | Is Connector | Is Male | Conn 7 Type | Conn 3 Type | Number Of Rows | Contact Finish Thickness | Conn 5 Type | Circuits | Contact Finish | Conn 6 Type | Conn 0 Type | Conn 4 Type | Conn 1 Type | Pitch | Conn 2 Type | Row Spacing | Resistor | Inductance | Nobom | Mechanical Details | Supplier 2 | Supplier 3 | Microchipcom Home | Supplier Part Number 1 | Supplier 4 | Supplier Part Number 3 | Packagedescription
C1 C10 C105 C106 C12 C14 C15 C16 C17 C18 C19 C2 C20 C21 C24 C25 C29 C3 C4 C44 C47 C48 C5 C51 C53 C54 C55 C58 C6 C60 C61 C64 C65 C66 C67 C68 C7 C71 C72 C73 C74 C77 C78 C79 C8 C9 C90 C82 | Generic Capacitor (Non-Polarized) (1e-07F) | Generic | Capacitor (1e-07F) |  | 0603 (1608 metric) | 48 | Capacitor | 1e-07F | 10v | 10% | true | X7R
C100 C11 C13 C86 C88 C89 | Generic Capacitor (Non-Polarized) (1e-05F) | Generic | Capacitor (1e-05F) |  | 0805 (2012 metric) | 6 | Capacitor | 1e-05F | 10v | 10% | true | X7R
C101 C103 C104 | Generic Capacitor (Non-Polarized) (4.7e-07F) | Generic | Capacitor (4.7e-07F) |  | 1206 (3216 metric) | 3 | Capacitor | 4.7e-07F | 100V | 10% | true | X7R
C22 C23 C26 C69 C70 C85 C94 C95 C96 C97 | Generic Capacitor (Non-Polarized) (4.7e-06F) | Generic | Capacitor (4.7e-06F) |  | 0805 (2012 metric) | 10 | Capacitor | 4.7e-06F | 10v | 10% | true | X7R
C31 C42 | Generic Capacitor (Non-Polarized) (1e-06F) | Generic | Capacitor (1e-06F) |  | 0805 (2012 metric) | 2 | Capacitor | 1e-06F | 10V | 10% | true | X7R
C32 C33 C40 | Generic Capacitor (Non-Polarized) (1e-08F) | Generic | Capacitor (1e-08F) |  | 1206 (3216 metric) | 3 | Capacitor | 1e-08F | 100V | 10% | true | X7R
C34 | Generic Capacitor (Non-Polarized) (1e-06F) | Generic | Capacitor (1e-06F) |  | 1206 (3216 metric) | 1 | Capacitor | 1e-06F | 100V | 10% | true | X7R
C46 | Generic Capacitor (Non-Polarized) (1.8e-08F) | Generic | Capacitor (1.8e-08F) |  | 0603 (1608 metric) | 1 | Capacitor | 1.8e-08F | 10v | 10% | true | X7R
C50 C52 C49 C57 C93 | Generic Capacitor (Non-Polarized) (1e-09F) | Generic | Capacitor (1e-09F) |  | 0603 (1608 metric) | 5 | Capacitor | 1e-09F | 10v | 10% | true | X7R
C62 | Generic Capacitor (Non-Polarized) (5e-11F) | Generic | Capacitor (5e-11F) |  | 0603 (1608 metric) | 1 | Capacitor | 5e-11F | 10v | 5% | true | COG
C84 C87 | Generic Capacitor (Non-Polarized) (1e-08F) | Generic | Capacitor (1e-08F) |  | 0603 (1608 metric) | 2 | Capacitor | 1e-08F | 10v | 10% | true | X7R
C92 | Generic Capacitor (Non-Polarized) (2.2e-11F) | Generic | Capacitor (2.2e-11F) |  | 0603 (1608 metric) | 1 | Capacitor | 2.2e-11F | 10v | 5% | true | COG
D10 D9 | Surface Mount Polymeric ESD Suppressors | Littelfuse Inc. | PGB1010603MR |  | 0603 (1608 metric) | 2 |  |  |  |  |  |  | 576-PGB1010603MR | TVS DIODE 24VWM 150VC 0603 | true | -65°C | true | F2594CT-ND | true | DIOCP16684X36 | true | +125°C | No
D11 | DIODE SCHOTTKY 20V 500MA 0603 | Comchip Technology | CDBU0520 |  | 603 | 1 |  |  |  |  |  |  |  |  |  |  |  |  |  | CAPC16080X45
D12 D14 D4 D5 D6 D7 D8 | 2.0x1.25mm SMD CHIP LED LAMP | Kingbright | APT2012SGC | Digi-Key 754-1131-6-ND/Digi-Key 754-1131-1-ND/Digi-Key 754-1131-2-ND | 0805 (2012 metric) | 7 |  | 15pF |  |  |  |  | 604-APT2012SGC | LED GREEN CLEAR 0805 SMD | true | -40°C | true | 754-1131-1-ND | true | DIOCP200125X45 | true | +85°C | No | octopart | Green Clear | LEDs | Optoelectronics | LEDs (Discrete) | Light Sources and Emitters
D2 D3 | High Conductance Ultra-Fast Switching Diode | Fairchild | BAV99 |  | SOT-23-3 | 2 |  |  | 70V |  |  |  | 512-BAV99 | DIODE ARRAY GP 70V 200MA SOT23-3 | true | -55 | true | BAV99FSCT-ND | true |  | true | 155 | No
J1 J16 | No description | AMPHENOL | 132357-11 |  | CONN_SMA_9MM52_7M92 | 2 |  |  |  |  |  |  |  |  |  |  |  |  |  |  |  |  | No |  |  |  |  |  |  | 50
J12 | Micro-USB B Receptacle with Flange, Bottom Mount, Surface Mount, | Molex | 47346-0001 |  | CONN_USB_2.0 | 1 |  |  |  |  |  |  | 538-47346-0001 | CONN RCPT 5POS MICRO USB R/A | true | -30°C | true | WM17141CT-ND | true |  | true | +85°C | No |  |  |  |  |  |  |  | Surface Mount, Right Angle | yes | yes
J13 | 2.54mm (0.1") Pitch Commercial/Industrial Connector | Harwin | M20-7820446 |  | CONN_SIL_SOCKET | 0 |  |  |  |  |  |  | 855-M20-7820446 | 04-WAY SIL VERT SOCKET L/FREE | true | -40°C | true | 952-1792-ND | true |  | true | +105°C | No |  |  |  |  |  |  |  |  |  | yes | yes
J14 J15 | PMOD 12 |  | PMOD12 |  | HDR12 | 2
J22 J23 | 2.54mm Pitch C-Grid® Breakaway Header, Dual Row, Vertical, High Temperature, 8 Circuits, 0.38µm Gold (Au) Selective Plating, Tin (Sn) PC Tail Plating, 2.72mm PC Tail | Molex | 10-89-7082 |  | HDR10 | 2 |  |  |  |  |  |  | 538-10-89-7082 | 8 Positions Header, Unshrouded, Breakaway Connector 0.100" (2.54mm) Through Hole Gold | false | -40°C | false | WM50012-08-ND | false |  | false | +105°C | No |  |  |  |  |  |  |  |  |  | yes | yes | passive | passive | 2 | 0.38µm | passive | 8 | Gold | passive | passive | passive | passive | 2.54mm | passive | 2.54mm
J5 | 40-Pin GPIO Through Holes for Raspberry Pi | N/A | 40-Pin Raspberry Pi B+ GPIO Through Holes |  | 40-Pin 2.54mm Pitch Through Holes | 0
L1 | Chip Ferrite Bead | MURATA | BLM21PG121SN1D |  | 0805 (2012 metric) | 1
L2 L3 L4 L5 L6 | Generic Inductor (1e-07H) | Generic | Inductor (1e-07H) |  | 0805 (2012 metric) | 5 | Inductor |  |  |  |  |  |  |  |  |  |  |  |  |  |  |  |  |  |  |  |  |  |  |  |  |  |  |  |  |  |  |  |  |  |  |  |  |  |  |  |  |  | 75R @100MHz | 1e-07H
M187 M188 M189 M190 M235 | Mounting Hole M3 | generic | Mounting Hole M3 |  |  | 5 |  |  |  |  |  |  |  |  |  |  |  |  |  |  |  |  | No
R1 R15 R16 R2 R25 R27 R28 R29 R3 R33 R34 R35 R4 R68 R69 R70 R45 R48 | Generic Resistor (10000) | Generic | Resistor (10000) |  | 0603 (1608 metric) | 18 | Resistor |  |  | 1% |  |  |  |  |  |  |  |  |  |  |  |  |  |  |  |  |  |  |  | 10000
R12 | Generic Resistor (100000) | Generic | Resistor (100000) |  | 1206 (3216 metric) | 1 | Resistor |  |  | 1% |  |  |  |  |  |  |  |  |  |  |  |  |  |  |  |  |  |  |  | 100000
R13 | Generic Resistor (280) | Generic | Resistor (280) |  | 0603 (1608 metric) | 1 | Resistor |  |  | 1% |  |  |  |  |  |  |  |  |  |  |  |  |  |  |  |  |  |  |  | 280
R17 | Generic Resistor (11000) | Generic | Resistor (11000) |  | 0603 (1608 metric) | 1 | Resistor |  |  | 1% |  |  |  |  |  |  |  |  |  |  |  |  |  |  |  |  |  |  |  | 11000
R18 R19 | Generic Resistor (100) | Generic | Resistor (100) |  | 0603 (1608 metric) | 2 | Resistor |  |  | 1% |  |  |  |  |  |  |  |  |  |  |  |  |  |  |  |  |  |  |  | 100
R21 R22 R56 | Generic Resistor (18R) | Generic | Resistor (18R) |  | 0603 (1608 metric) | 3 | Resistor |  |  | 1% |  |  |  |  |  |  |  |  |  |  |  |  |  |  |  |  |  |  |  | 18R
R24 R26 R30 R31 R74 | Generic Resistor (649R) | Generic | Resistor (649R) |  | 0603 (1608 metric) | 5 | Resistor |  |  | 1% |  |  |  |  |  |  |  |  |  |  |  |  |  |  |  |  |  |  |  | 649R
R32 R57 | Generic Resistor (2K2) | Generic | Resistor (2K2) |  | 0603 (1608 metric) | 2 | Resistor |  |  | 1% |  |  |  |  |  |  |  |  |  |  |  |  |  |  |  |  |  |  |  | 2K2
R44 | Generic Resistor (DNP) | Generic | Resistor (DNP) |  | 0603 (1608 metric) | 0 | Resistor |  |  | 1% |  |  |  |  |  |  |  |  |  |  |  |  |  |  |  |  |  |  |  | DNP |  |  |  |  |  |  |  |  |  |  |  |  |  |  |  |  |  |  |  |  | true
R46 | Generic Resistor (1800) | Generic | Resistor (1800) |  | 0603 (1608 metric) | 0 | Resistor |  |  | 1% |  |  |  |  |  |  |  |  |  |  |  |  |  |  |  |  |  |  |  | 1800
R47 | Generic Resistor (10000) | Generic | Resistor (10000) |  | 0603 (1608 metric) | 0 | Resistor |  |  | 1% |  |  |  |  |  |  |  |  |  |  |  |  |  |  |  |  |  |  |  | 10000 |  |  |  |  |  |  |  |  |  |  |  |  |  |  |  |  |  |  |  |  | false
R50 R51 R75 | Generic Resistor (1000000) | Generic | Resistor (1000000) |  | 0603 (1608 metric) | 3 | Resistor |  |  | 1% |  |  |  |  |  |  |  |  |  |  |  |  |  |  |  |  |  |  |  | 1000000
R52 | Generic Resistor (357000) | Generic | Resistor (357000) |  | 0603 (1608 metric) | 1 | Resistor |  |  | 1% |  |  |  |  |  |  |  |  |  |  |  |  |  |  |  |  |  |  |  | 357000
R53 | Generic Resistor (210000) | Generic | Resistor (210000) |  | 0603 (1608 metric) | 1 | Resistor |  |  | 1% |  |  |  |  |  |  |  |  |  |  |  |  |  |  |  |  |  |  |  | 210000
R54 R55 | Generic Resistor (100R) | Generic | Resistor (100R) |  | 1206 (3216 metric) | 2 | Resistor |  |  | 1% |  |  |  |  |  |  |  |  |  |  |  |  |  |  |  |  |  |  |  | 100R
R6 | Generic Resistor (12000) | Generic | Resistor (12000) |  | 0603 (1608 metric) | 1 | Resistor |  |  | 1% |  |  |  |  |  |  |  |  |  |  |  |  |  |  |  |  |  |  |  | 12000
R7 | Generic Resistor (2200) | Generic | Resistor (2200) |  | 0603 (1608 metric) | 1 | Resistor |  |  | 1% |  |  |  |  |  |  |  |  |  |  |  |  |  |  |  |  |  |  |  | 2200
R72 R73 | Generic Resistor (0) | Generic | Resistor (0) |  | 0603 (1608 metric) | 0 | Resistor |  |  | 1% |  |  |  |  |  |  |  |  |  |  |  |  |  |  |  |  |  |  |  | 0
SW100 SW221 SW94 SW97 | Tactile Switches SPST OFF-(ON) 3VA BLK FLAT BUTTON SMT | NKK | HP0315AFKP2-R |  | SW_6MM2_6MM2_SMT_4 | 4 |  |  |  |  |  |  | 633-HP0315AFKP2-R | SWITCH TACTILE SPST-NO 3VA 28V | true | -20°C | true | 360-2595-1-ND | true |  | true | +70°C | No
U1 | ultra-low power, non-volatile FPGA | Lattice | iCE40HX4K-TQ144 |  | TQFP144 | 1 |  |  |  |  |  |  | 842-ICE40HX4K-TQ144 | IC FPGA 107 I/O 144TQFP | true | -40°C | true | 220-1572-ND | true | QFP50P2200X2200X160-144 | true | +100°C | No |  |  |  |  |  |  |  |  |  |  |  |  |  |  |  |  |  |  |  |  |  |  |  |  |  |  |  |  | http://www.latticesemi.com/~/media/LatticeSemi/Documents/PinPackage/PackageDiagrams.pdf
U112 U206 U207 U208 | Triple non-inverting Schmitt trigger with 5 V tolerant input | NEXPERIA | 74LVC3G17DP |  | TSSOP8 | 4 |  |  |  |  |  |  |  |  |  |  |  |  |  | SOP65P400X105-8 |  |  |  |  |  |  |  |  |  |  |  |  |  |  | passive | passive |  |  | passive |  |  | passive | passive | passive | passive |  | passive
U13 | Dual High Speed USB to Multipurpose UART/FIFO IC | Future Technology Devices International Ltd. | FT2232HL-REEL |  | LQFP64 | 1 |  |  | 3.6V |  |  |  | 895-FT2232HL | IC USB HS DUAL UART/FIFO 64-LQFP | true | -40°C | true | 768-1024-1-ND | true | QFP50P1200X1200X160-64 | true | +85°C | No
U157 | 2K, 128x16-bit, 2.5V Microwire Serial EEPROM, 6-Pin SOT-23, Industrial Temperature, Tape and Reel | Microchip | 93LC56BT-I/OT | Digi-Key 93LC56BT-I/OTCT-ND/Digi-Key 93LC56BT-I/OTDKR-ND/Digi-Key 93LC56BT-I/OTTR-ND/Newark 28X4163/Newark 30H4760 | SOT-23 | 0 |  |  |  |  |  |  |  |  |  |  |  |  |  |  |  |  |  | Altium |  |  |  |  |  |  |  |  |  |  |  |  |  |  |  |  |  |  |  |  |  |  |  |  |  |  |  |  | Digi-Key | Digi-Key | http://www.microchip.com/ | 93LC56BT-I/OTTR-ND | Farnell | 93LC56BT-I/OTDKR-ND | 6-Lead Plastic Small Outline Transistor (OT) [SOT-23]
U169 | Dual 750mA/250mA Low Dropout, Low Noise, Micropower Linear Regulator | LINEAR TECHNOLOGY | LT3030 |  | TSSOP20 | 1 |  |  |  |  |  |  |  |  |  |  |  |  |  |  |  |  |  |  |  |  |  |  |  |  |  |  |  |  | passive | passive |  |  | passive |  |  | passive | passive | passive | passive |  | passive
U179 | 10-Bit Voltage Output Digital-to-Analog Converter with Internal VREF and SPI Interface | Microchip | MCP4811-E/MS |  | MSOP8 | 1 |  |  |  |  |  |  |  |  |  |  |  |  |  | SOIC65P490X110-8 |  |  |  | PartsBot |  |  |  |  |  |  |  |  |  |  | passive | passive |  |  | passive |  |  | passive | passive | passive | passive |  | passive
U182 | 3V 8M-BIT SERIAL FLASH MEMORY WITH DUAL/QUAD SPI | WINBOND | W25Q80JVSNIQ |  | SO8 | 1
U236 | Voltage Supervisor with Manual Reset Input, 4-Pin SOT-143, VTRIP:3.00V (min.) / 3.08V (typ.) / 3.15V (max.), Tape and Reel | Microchip | TC1270ATAVRCTR |  |  | 1 |  |  |  |  |  |  |  |  |  |  |  |  |  |  |  |  |  | Altium |  |  |  |  |  |  |  |  |  |  |  |  |  |  |  |  |  |  |  |  |  |  |  |  |  |  |  |  |  |  | http://www.microchip.com/ |  |  |  | 4-Lead Plastic Small Outline Transistor (RC) [SOT-143]
U241 U247 | Quad 1-of-2 multiplexer/demultiplexer | NEXPERIA | 74CBTLV3257PW |  | SOP65P640X120-16N | 2 |  |  |  |  |  |  |  |  |  |  |  |  |  | SOP65P640X105-16 |  |  |  |  |  |  |  |  |  |  |  |  |  |  | passive | passive |  |  | passive |  |  | passive | passive | passive | passive |  | passive
U36 | High Speed Dual MOSFET Driver | MICROCHIP | MD1210K6-G |  | QFN12 | 1 |  |  |  |  |  |  |  |  |  |  |  |  |  | QFN80P400X400X90-12 |  |  |  |  |  |  |  |  |  |  |  |  |  |  | passive | passive |  |  | passive |  |  | passive | passive | passive | passive |  | passive
U40 | Standard | Supertex | TC6320TG-G |  | SO | 1 |  |  |  |  |  |  |  |  |  |  |  |  |  | SOIC127P600X155-8 |  |  |  |  |  |  |  |  |  |  |  |  |  |  | passive | passive |  |  | passive |  |  | passive | passive | passive | passive |  | passive
U54 | Triple Output 3W DC/DC Converters | MURATA | NMT0572SC |  | SIP8 | 1 |  |  |  |  |  |  |  |  |  |  |  |  |  | SIP750W50P254L2180H1110Q8 |  |  |  |  |  |  |  |  |  |  |  |  |  |  |  | passive |  |  | passive |  |  |  | passive | passive | passive |  | passive
U61 | HIGH VOLTAGE PROTECT T/R SWITCH | MICROCHIP | MD0100N8-G |  | SOT89-3 | 1 |  |  |  |  |  |  |  |  |  |  |  |  |  |  |  |  |  |  |  |  |  |  |  |  |  |  |  |  |  |  |  |  |  |  |  |  | passive |  | passive |  | passive
U64 |  | ANALOG DEVICES | AD8331ARQZ | Digi-Key AD8331ARQZ-ND/Newark 59K6617 | SOP64P600X165-20N | 1 |  |  |  |  |  |  |  |  |  |  |  |  |  |  |  |  |  | Eagle
U79 | 10-Bit 65 MSPS 3V A/D Converter, 28-pin TSSOP, Pb-Free | National Semiconductor | ADC10065CIMT/NOPB |  |  | 1 |  |  |  |  |  |  |  |  |  |  |  |  |  |  |  |  |  | Altium |  |  |  |  |  |  |  |  |  |  |  |  |  |  |  |  |  |  |  |  |  |  |  |  |  |  |  |  |  |  |  | ADC10065CIMT-ND |  |  | Molded TSSOP, Jedec, 9.7 x 4.4 x 0.9mm Body, 28 Lead, 0.65mm Pitch
U89 | 512K x 16 HIGH-SPEED ASYNCHRONOUS CMOS STATIC RAM WITH 3.3V SUPPLY | ISSI | IS61WV51216BLL-10TLI |  | SOP80P1176X120-44N | 1 |  |  |  |  |  |  |  |  |  |  |  |  |  | SOP80P1176X105-44 |  |  |  |  |  |  |  |  |  |  |  |  |  |  | passive | passive |  |  | passive |  |  | passive | passive | passive | passive |  | passive
X1 | Standard Clock Oscillators 12.000MHZ 50ppm -40 + 85C | ABRACON | ASEMB-12.000MHZ-LC-T |  | XTAL_SMD_3MM2_2MM5 | 1
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

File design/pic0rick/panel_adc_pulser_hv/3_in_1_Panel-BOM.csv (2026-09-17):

Comment | Designator | Footprint | MPN | Manufacturer | LCSC Part #
22pF | C12 | C_1206_3216Metric | VJ1206A220JXQPW1BC
50pF | C20 | C_1206_3216Metric | 12062A500KAT2A | KYOCERA AVX
1nF | C18,C21,C23 | C_1206_3216Metric | GRM31C5C3A102JWA3L
10nF | C29,C30,C31 | C1206 | FCC1206B103K500DT | FOJAN(富捷)
18nF | C6 | C_1206_3216Metric | VJ1206Y183KXAAC
100nF | C1,C2,C4,C5,C8,C9,C10,C11,C13,C14,C15,C16,C17,C19,C22,C24,C26 | C_1206_3216Metric | VJ1206Y104KXQCW1BC
100nF | C27,C28,C32,C33,C36,C37,C38 | C1206 | CL31B104KBCNNNC | SAMSUNG(三星)
1uF | C34,C35,C39,C42 | C1206 | CL31B105KBHNNNE | SAMSUNG(三星)
4.7uF | C3,C7 | C_1206_3216Metric | 1206ZD475KAT4A
4.7uF | C40,C41 | C1206 | UMK316AB7475KL-T | TAIYO YUDEN(太诱)
10uF | C25 | C_1206_3216Metric | KAF31GR71C106KU | KYOCERA AVX
BAV99 | D2 | SOT-23-3_L2.9-W1.3-P1.90-LS2.4-BR | BAV99 | DIODES(美台)
BAV99 | D4 | SOT-23-3_L2.9-W1.3-P1.90-LS2.4-BR | BAV99-7-F | DIODES(美台)
BAV99-7-F | D1 | SOT95P240X120-3N | BAV99-7-F
Green LED | D3 | LED0805-R-RD | NCD0805G1 | 国星光电
120Ohm 3 A | FB6,FB7 | L1206 | CBW321609U121T | FH(风华)
ILHB1206ER750V | FB1,FB2,FB3,FB4,FB5 | L_1206_3216Metric | BLM21BB750SN1D
TC74VHC08F_EL,K,F_ | H1 | SOP-14_L10.2-W5.3-P1.27-LS7.8-BL | TC74VHC08F_EL,K,F_ | TOSHIBA(东芝)
AD8331ARQZ | IC2 | SOP64P600X175-20N | MD1213K6-G
ADC10065CIMT_NOPB | IC1 | SOP65P640X120-28N | SN74LVC2G04DBVT
MCP4812-E_MS | IC3 | MCP4812-EMS | 579-MCP4812-E/MS
MD1213K6-G | IC4 | QFN-12_L4.0-W4.0-P0.80-BL-EP1.7 | SN74LVC2G04DBVT | MICROCHIP(美国微芯)
MD1213K6-G | IC5 | QFN-12_L4.0-W4.0-P0.80-BL-EP1.7 | MD1213K6-G | MICROCHIP(美国微芯)
SN74LVC2G04DBVT | IC6 | SOT-23-6_L2.9-W1.6-P0.95-LS2.8-BR | TC6320TG-G | TI(德州仪器)
SN74LVC2G04DBVT | IC9 | SOT-23-6_L2.9-W1.6-P0.95-LS2.8-BR | SN74LVC2G04DBVT | TI(德州仪器)
TC6320TG-G | IC7,IC8 | SOIC-8_L4.9-W3.9-P1.27-LS6.0-BL | TC6320TG-G | MICROCHIP(美国微芯)
61300411121 | J4 | PinHeader_1x04_P2.54mm_Vertical | 61300411121
61300611021 | J9 | HDR-TH_6P-P2.54-H-M-W10.3 | HX PZ2.54-1x6P WZ | hanxia(韩下)
61300611121 | J3 | PinSocket_1x06_P2.54mm_Horizontal | 61300611021
90122-0126 | J6 | PinSocket_2x06_P2.54mm_Horizontal | 613012243121
AMPHENOL_132357-11 | J1 | AMPHENOL_132357-11 | 132357-11
Conn_01x02 | J8 | HDR-TH_2P-P2.54-H-M-R2-C1_TSW-101-08-XXX-D-RA | HTSW-101-08-T-D-RA | SAMTEC
Conn_01x02_Pin | J11 | HDR-TH_2P-P2.54-V-M | PZ254V-11-02P | XFCN(兴飞)
Conn_01x02_Socket | J13 | HDR-TH_2P-P2.54-V-F | ZX-PM2.54-1-2PY | Megastar(兆星)
Conn_01x03_Pin | J10 | HDR-TH_3P-P2.54-V-M_PZ254V-11-03P | PZ254V-11-03P | XFCN(兴飞)
Conn_01x03_Socket | J14 | HDR-TH_3P-P2.54-V-F | HC-PM254-8.5H-1x3PZ-02A | HC(虹成电子)
SSQ-101-02-L-Q-RA | J2,J5,J7 | PinHeader_1x02_P2.54mm_Vertical | SSQ-101-02-L-Q-RA
6.8uH | L1 | L1206 | ILSB1206ER6R8K | VISHAY(威世)
R2D-0524_P | PS1 | PWRM-SMD_R2D-XXXX | R2D-0524 | Recom Power
18R | R1,R10,R11 | R_1206_3216Metric | WSL1206R1800FEA
100R | R4,R8 | R_1206_3216Metric | 560112132023
280R | R7 | R_1206_3216Metric | CR1206-FX-2800ELF | Bourns
1K | R12 | R1206 | FRC1206J102 TS | FOJAN(富捷)
10K | R13,R14,R15 | R1206 | FRC1206F1002TS | FOJAN(富捷)
10K | R2,R3,R5,R6 | R_1206_3216Metric | 1206W4F1002T5E
12K | R9 | R_1206_3216Metric | CR1206-FX-1202ELF | Bourns
MD0100N8-G | U1 | SOT-89-3 | MD0100N8-G
Pico | U2 | RPi_Pico_SMD | Pico
VAL** | mouse-bite-3mm-slot | mouse-bite-3mm-slot

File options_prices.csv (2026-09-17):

category | option_group | part | function | key_spec | price_usd_lcsc | stock | source_url | notes
mcu | - | RP2350B | controller | dual Cortex-M33 + PIO | 1.06 | in_stock | https://www.lcsc.com/product-detail/C42415655.html | RP2350A ~1.03 (C42411118)
pulser | unipolar_5v | note_5V_only | use USB 5V as +HV directly | no boost IC; FET+driver+T/R only | 0.00 | - | - | cheapest HV path; low amplitude; upgrade via HV header (T7)
pulser | unipolar | HV_NMOS_100V | TX FET | single ~100V N-MOSFET | 0.30 | in_stock |  | indicative; generic jelly-bean MOSFET (look up exact PN)
pulser | unipolar | gate_driver | MOSFET gate driver | e.g. UCC27511 / TC4420 | 0.50 | in_stock |  | indicative; generic (look up exact PN)
pulser | unipolar | boost_HV | HV boost supply IC | e.g. LT3494 / TPS6139x | 1.00 | in_stock |  | indicative; inductor is a passive
pulser | bipolar | MD1213 | 3-state pulser driver | drives +/-100V P/N FETs |  | not_found | https://www.microchip.com/en-us/product/md1213 | NOT found on LCSC — may not be JLCPCB-stocked; verify / alt distributor
pulser | bipolar | TC6320 | HV MOSFET pair | +/-100V 2A P+N (TG-G) | 2.03 | in_stock | https://www.lcsc.com/product-detail/C624992.html | 1251 in stock; K6-G ~2.37 (C624991)
pulser | bipolar_5v | neg5v_chargepump | generate -5V from +5V | LM2776DBVR SOT-23 | 0.48 | in_stock | https://lcsc.com/product-detail/C69527.html | cheap symmetric +/-5V rail (T6/B0)
pulser | bipolar | neg_rail_inv | inverting supply for higher - rail | e.g. LT3463 / TPS6040x | 3.00 | check |  | indicative; higher-voltage bipolar only
pulser | integrated | STHV748 | pulser + T/R (quad) | +/-90V 3/5-level +T/R | 10.00 | check | https://www.st.com/en/switches-and-multiplexers/sthv748s.html | indicative; verify LCSC stock
support | tr_switch | MD0100 | T/R switch | passive HV limiter | 3.00 | check |  | indicative; verify LCSC stock; not needed w/ STHV748/TUSS
gain | vga | AD8331 | LNA+VGA+postamp | 48 dB to 120 MHz (ARQZ) | 10.00 | in_stock | https://www.lcsc.com/product-detail/C203731.html | proven un0rick/pic0rick/IUP (DP5); IN STOCK
gain | vga | AD8338 | low-power VGA | 0-80 dB single-ended | 4.00 | out_of_stock | https://www.lcsc.com/product-detail/Special-Purpose-Amplifiers_Analog-Devices-AD8338ACPZ-RL_C652715.html | cheaper/low-power BUT OUT OF STOCK at LCSC
gain | vga | AD8330 | low-cost VGA | ~50 dB DC-150 MHz diff | 6.00 | check |  | indicative; verify LCSC stock
gain | vga | AD603 | cheap VGA | ~40 dB 90 MHz | 4.00 | check |  | indicative; needs external LNA
gain | lna | LNA_opamp | LNA for AD603/AD8367 | low-noise op-amp | 1.00 | in_stock |  | indicative; generic
gain | gain_ctrl | MCP4812 | DAC for TGC ramp | 12-bit dual SPI | 1.50 | check |  | optional; RP2350 PWM+RC = 0
adc | ext | AD9235-20 | external ADC | 12-bit 20 MSps parallel | 17.88 | in_stock | https://lcsc.com/product-detail/C514274.html | IN STOCK but pricier than expected; -40 (C-?) more
adc | ext | AD9200 | external ADC | 10-bit 20 MSps parallel | 4.72 | out_of_stock | https://www.lcsc.com/product-detail/Analog-To-Digital-Converters-ADCs_Analog-Devices-AD9200ARSZRL_C653235.html | cheap BUT OUT OF STOCK at LCSC
adc | ext | AD9280 | external ADC | 8-bit 32 MSps parallel | 4.00 | check |  | indicative; ~48 dB only (marginal vs P5)
adc | ext | TLC5540 | external ADC | 8-bit 40 MSps parallel | 3.00 | check | https://www.ti.com/product/TLC5540 | cheap 8-bit; verify LCSC stock; ~48 dB (marginal vs P5)
adc | ext | ADS830 | external ADC | 8-bit 60 MSps parallel | 4.00 | check | https://www.ti.com/product/ADS830 | cheap 8-bit; verify LCSC stock
adc | ext | ADC10065 | external ADC | 10-bit 65 MSps parallel | 10.00 | check |  | un0rick/pic0rick (DP5); verify LCSC stock
adc | ext | LTC2203 | external ADC | 16-bit 25 MSps parallel | 25.00 | check |  | IUP; high DR | pricey/large
adc | internal | RP2350_ADC | internal ADC | 12-bit 500 kSps | 0.00 | - | - | envelope-only; too slow for 3-4 MHz raw RF

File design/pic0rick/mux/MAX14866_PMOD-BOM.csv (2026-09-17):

Comment | Designator | Footprint | MPN | Manufacturer | LCSC Part #
100nF | C3 | C_1206_3216Metric
1uF | C2 | C_1206_3216Metric
22-23-2021 | J6 | PinSocket_2x01_P2.54mm_Horizontal | 22-23-2021
22-23-2021 | J7 | PinHeader_2x01_P2.54mm_Horizontal | 22-23-2021
90122-0126 | J2 | PinHeader_2x06_P2.54mm_Horizontal | 90122-0126
90122-0126 | J4 | PinSocket_2x06_P2.54mm_Horizontal | 90122-0126
AMPHENOL_132357-11 | J1,J3 | AMPHENOL_132357-11-MOD | AMPHENOL_132357-11
Conn_02x08_Odd_Even | J5 | PinHeader_2x08_P2.54mm_Vertical
10R | R1 | R_1206_3216Metric
10K | R2,R3 | R_1206_3216Metric
MAX14866UTM+T | U2 | 21-0144H_T4877-6_MXM

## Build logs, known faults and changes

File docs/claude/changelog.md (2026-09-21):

# Changelog

Summary of every commit to this repo, newest first.
Format: `YYYY-MM-DD  <short-sha>  summary`.

Uncommitted work sits at the top under "Pending" until it lands, then it gets
the sha.

## Pending

- (none)

## Committed

- 2026-09-21  c8eb87d  Add `design/devkit/review-findings.md` (4-agent flaw review, ranked +
  fix tracker); apply datasheet corrections across pic32/designA/devkit/pcb-brief (VREF=AVDD,
  op-amp HP/LP 100/50 MHz + ±3mV, ENOB ~10.5, TC4427A no dead-time/8-pin, edges ~20–30ns);
  pcb-brief §0 must-fix-before-layout; memory `0007-designA-devkit.md` (+INDEX).

- 2026-09-21  a05eef6  Add standalone `design/devkit/pcb-brief.md` — one-file PCB-designer
  handoff (overview + mermaid, power/clocks, programming, inter-MCU bus, pulser, jumper-
  selected RX front-ends + gain + ADC conditioning, connectors/taps, layout, deliverables,
  refs); linked from devkit README.

- 2026-09-21  9ba7a33  `design/devkit/`: shareable **PCB designer brief** (B1–B11) — board
  scope, power/clocks, dual programming, inter-MCU bus, pulser bench, jumper-selected RX
  front-ends + gain-control + ADC input conditioning, connectors/taps, layout guidance,
  deliverables, references.

- 2026-09-21  4a272f2  ADC input conditioning (DesignA §5a: single-supply 0→VREF, mid-rail
  bias, ~2.8 Vpp fit, clamp) + TX↔ADC hardware trigger (§5b: HS-PWM/PTG, PIC-owns-TX);
  requirements **A5**+**C1c**; pic32 §4/§3d + devkit derisk rows. Mirror full PIC32AK
  **datasheet DS70005592** (36 MB) + **flash-prog-spec DS70005583** with `.md` siblings.

- 2026-09-21  a533a39  `design/devkit/`: single board, **jumper-selected** RX paths
  (JIN_*/JOUT_* route one of FE-0…FE-D from RX node to ADC node) — no mezzanine/
  daughter-cards; gain-control via on-board jumper block; down-spec to DesignA =
  depopulate losers.

- 2026-09-21  dced415  Add `design/devkit/` — **DesignA-DK** derisking board: RP2354A +
  PIC32AK6416 (64-pin/16KB), fully broken out, swappable RX front-ends (FE-0 … FE-C/D ext
  VGA), gain-control options (I²C/SPI digipot, resistor-mux, VGA Vgain), pulser bench,
  split rails, SMA taps + loopback self-test; derisk-priority + vendor-eval path.

- 2026-09-18  d66d17c  DesignA: Ubuntu CLI+Makefile toolchain (`toolchain_designA.md`:
  RP2354 pico-sdk→uf2, PIC32A XC-DSC→hex via ipecmd/PICkit) + reuse of **kelu124/pic32arick**
  blocks — push-pull pulser (IRLML6244/2244 + TC4427A), 3-op-amp gain (OA1 fixed + MCP4531
  I²C digipot OA2 + bias OA3), MD0100 T/R, 6-pin ICSP (47Ω + Tag-Connect + off-center
  friction-fit holes). BOM ≈ $4.7 active / $6.3 board (min $5.4); pic32arick → memory 0004.

- 2026-09-18  d663709  DesignA: PIC32 direct-flash (S4a + `design/pic32/pic32.md` ICSP/
  PICkit/LVP/MCLR), pulser drive-select jumper JP1 (T4a: PIC32 HS-PWM ⟷ RP2354 PIO),
  J3 ICSP header, §6b programming, and mermaid diagrams (block / programming / sequence).

- 2026-09-18  75ad246  Add `design/designA/` — **DesignA**, the cheapest *minus* build:
  RP2354A + PIC32A, unipolar 5 V N-FET pulser (options.md U0), digipot-set per-line gain,
  PIC on-die 40 Msps ADC; active-IC BOM ≈ $3.7 / board ≈ $5. RP2354A on LCSC/JLC
  (C41378174, ~$1.27); PIC32A the only non-LCSC part.

- 2026-09-18  f219638  LCSC prices for gain/LNA ICs — price table in
  `systems/afe-vga-ics.md` + refreshed `options.md` §2. AD8331 ~$14 (in stock),
  AD603 ~$9 + $5 LNA in stock, AD8338/AD8332 OOS, LMH6629/ADA4898-1/OPA847 ~$5 in stock;
  VCA810/AD8432/AFE5808/AD9276 not LCSC-stocked (Digikey).

- 2026-09-18  90cdf6a  `systems/afe-vga-ics.md`: LNA-pairing section for VGA-only parts
  (VCA810 2.4 / AD603 1.3 nV/√Hz need a <1 nV/√Hz LNA) — OPA847/LMH6629/AD8099/AD797/
  ADA4898 op-amp LNAs + AD8432 dedicated ultrasound LNA; T/R protection; integrated-LNA
  VGAs (AD8331/AD8338/AFE5808) dominate real reference designs.

- 2026-09-18  160c089  Add `systems/afe-vga-ics.md` — survey of RX gain ICs (LNA +
  variable-gain / AFE), single-channel → 8/16-channel (AD833x, AD8338, AD603/VCA810,
  AD8332/VCA26xx, AD8334/AFE5401, AFE5808/AD9276-family/MAX2082, VCA5807, AFE5832);
  linked from systems/README, by-ic.md, options.md §2.

- 2026-09-18  0bbbd34  Confirm (RP2350 datasheet) RP2354A = 2 MB in-package flash, no
  external flash chip (QSPI_IOVDD 3.3V); BOOTSEL button wires QSPI_CSn→GND via ~1kΩ
  (same as flashless RP2350A), optionally paired with a RUN reset button.

- 2026-09-18  3b3fba3  PIC32A: LCSC/JLCPCB **not stocked** (→ consigned/Digikey);
  add `6416` (64/16) flash tier; §3c **Footprint** guidance (48-pin VQFN ~6×6 mm since
  board is already QFN; shrink RP2350 to RP2350A/RP2354A QFN-60 7×7).

- 2026-09-18  bbd048a  Session 02: `activities/possibilities.md` (workshop activity
  menu); `requirements.md` §19 anti-requirements (N1–N11) + TGC dropped (F6 per-line
  settable gain, A3/A3a/P8/A1/§17); `design/pic32/` concept (PIC32A + RP2350: BOM,
  5V pulser, gain, §3c chip choice, §3d interconnect; Digikey ~$1.6–1.9, LCSC TBD);
  new rule — Markdown sibling for every PDF via markitdown (+ `.md` for all 11 PDFs).
- 2026-09-17  828d364  Record cheaper 8-bit ADC candidates (TLC5540/ADS830/AD9280) to
  verify on LCSC; ADEC remains the open cost driver. **Pushed.**
- 2026-09-17  4c6f5cb  Real LCSC prices+URLs+stock in options; ADC bottleneck (~$33
  in-stock front-end); TXRX-LINK open question. **Pushed.**
- 2026-09-17  bc967b2  options.md trade study + options_prices.csv; analysis §3b gain
  options; 5V/±5V HV options; requirements RF-ACCESS; memory 0006. **Pushed.**

## Committed

- 2026-09-17  1a6975b  requirements: plan OSHWA cert + reserve silkscreen for the mark/UID.
- 2026-09-17  785d3c0  requirements v0.3 refinements: bipolar-if-cheap-±rail (T6),
  on-device DSP demo (S6), autonomous RGB LED (F11).
- 2026-09-17  d7f7b79  requirements.md v0.3: NDT/workshop-badge, 3–4 MHz, unipolar,
  A-/M-mode, coded excitation, multi-connector (SMA/header/uFL), precise-timing +
  gap-free-ADC controller, DP5 derisk-by-reuse, provided piezo, on-body safety.
- 2026-09-17  b21abac  requirements.md v0.2: RP2350 MCU + on-board USB-C bus-powered +
  DP1–DP4 (small/cheap/simple); external-ADC note; memory 0005. **Pushed.**

- 2026-09-17  6b64555  Draft root `requirements.md` (v0.1, MoSCoW + open-decision
  TBDs); cross-link from analysis.md; memory 0005 + docs. **Pushed.**

- 2026-09-17  0dea95f  Per-system "Piezo 1–5 MHz" + "ADC sampling" attributes (19
  sheets + template + quick-ref); root `analysis.md` (routes + light-BOM pulsers);
  `pdfs/datasheets/` pulser datasheets; memory 0005. **Pushed.**
- 2026-09-17  622bb3d  `systems/by-ic.md` (MSP430FR5043 + TUSS4470 cross-reference),
  Open Echo datasheet, `design/{biogap-wulpus-pro,open-echo}/` files. **Pushed.**
- 2026-09-17  6e0b07f  SIG-WUS OXP catalog snapshot (`systems/_sig-wus-oxp/`);
  FloPatch detail (FP120, CW 4 MHz, FDA/CE, Kenny 2021); SENS-U → TENA/Essity;
  BioGAP WULPUS-pro sheet; 45 MB per-file cap. **Pushed to origin/main.**
- 2026-09-17  25b8e55  Pull reference design files (`design/{un0rick,lit3rick,
  pic0rick}/` + SOURCE.md); process Weik et al. 2026 wearables review + SIG-WUS
  (Table I → `systems/literature.md`); add SENS-U/WMAUS/MoUsE/Flopatch sheets +
  memory 0004.
- 2026-09-17  0dd9e66  Add IUP + MEMS-US datasheets, `systems/literature.md` (from
  Jonveaux et al. 2022 review), and `pdfs/` + `design/` folders with store
  conventions; RP2350 datasheet added to `pdfs/`.
- 2026-09-17  bab55c6  Extend `systems/` survey (online research): Murgen, un0rick,
  lit3rick, TUSS4470 sheets; 5-branch README framing; out-of-scope (64+ elements)
  + leads-to-review sections.
- 2026-09-17  82c24e3  Add `systems/` lightweight-ultrasound survey: datasheet
  TEMPLATE.md, index README, and 7 populated sheets (EchoLite, PuLsE, USoP,
  WULPUS, WULPUS PRO, pic0rick, TinyProbe).
- 2026-09-17  beffd20  Set up Claude documentation & memory system (docs/claude/
  logs, memory store, TODO/DONE, changelog), CLAUDE.md rules, and the repo-scoped
  `minus-docs` skill.
- 2026-09-17  f3d8367  Initial commit.

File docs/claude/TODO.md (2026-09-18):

# TODO

Open work items for **minus**. Newest ideas at the top of their section.
When an item is finished, move it to [`DONE.md`](DONE.md) with the date.

## Now

- Requirements v0.3: NDT/workshop-badge, 3–4 MHz, unipolar, A-/M-mode, RP2350 + USB-C,
  provided piezo, coded excitation, multi-connector, derisk-by-reuse (DP5) all locked.
  Only ADEC (external ADC choice) + exact HV level remain open.
- Confirm **RF-ACCESS** (raw RF vs envelope) — gates the external-ADC section.
- Pick from `options.md`: pulser (U0/U1/U2/B0), gain (AD8338 vs AD8331), ADC
  (AD9200/AD9235); refresh `options_prices.csv` from live LCSC (qty 20–50).
- Then draft a **costed BOM + block diagram** reusing un0rick/pic0rick blocks on RP2350.
- **PIC32A concept** (`design/pic32/`): evaluate RP2350 + PIC32AK3208GC41064 (on-die
  40 Msps ADC + 100 MHz op-amps) as an alternative to external ADC+VGA. Open:
  - Confirm **LCSC stock + JLCPCB assembly** for the PIC32A (Digikey ~$1.6–1.9 known;
    LCSC/JLCPCB TBD — the go/no-go for the project's fab flow).
  - Verify whether the PIC32A op-amp has an **internal PGA (GSEL) ladder** (→ per-line
    gain with zero extra parts) or needs an external **digipot/MDAC/resistor-mux**.
  - Check PIC32A op-amp **input noise** vs echo level → decide if a fixed **LNA** (A3a)
    first stage is needed.
  - Decide TX sequencer ownership (PIC32A HS-PWM+PTG vs RP2350 PIO) + inter-MCU SPI
    protocol; test **ICSP-from-RP2350** (one USB port programs both).

## Next

- (optional) Mirror the full BioGAP Altium source + gerbers, and the Open Echo
  firmware/Python interface, if wanted beyond the current schematic+fab files.
- Sheet remaining leads: Measurement-2024 compact modular platform (32 el., get PDF
  → `pdfs/`), rtl-ultrasound (Meng 2019, SDR), compressive single-sensor 3D
  (Kruizinga 2017); optionally Bashatah (chirp) + Wang (Barker) from Weik Table I.
- Confirm lit3rick `[E]` fields from `design/lit3rick/lit3rick_schematics.pdf`.
- Collect more design files (IUP if released); add `design/` subfolders as sheeted.
- Fill survey gaps: EchoLite (await IEEE IUS 2025 paper), PuLsE/USoP MCU parts & TX
  voltages, pic0rick dimensions/SNR.
- Advance `analysis.md`: fix minus target frequency, unipolar vs bipolar, pick
  pulser (STHV748 vs MD1213+TC6320 vs unipolar), ADC + controller; then draft a BOM.
- Decide which reference systems `minus` derives from (kelu124 family / IUP / WULPUS
  / PuLsE / TUSS4470 route).

- Define target application, imaging depth, and centre frequency.
- Choose the single-element transducer and how (or whether) it scans.
- Decide pulser / analog front-end approach.
- Decide digitizer / ADC and sampling strategy.
- Decide compute/host (MCU, FPGA, PC) and display path.

## Someday / maybe

- Review prior work in sibling repos (e.g. `we_gate`) for reusable pieces.

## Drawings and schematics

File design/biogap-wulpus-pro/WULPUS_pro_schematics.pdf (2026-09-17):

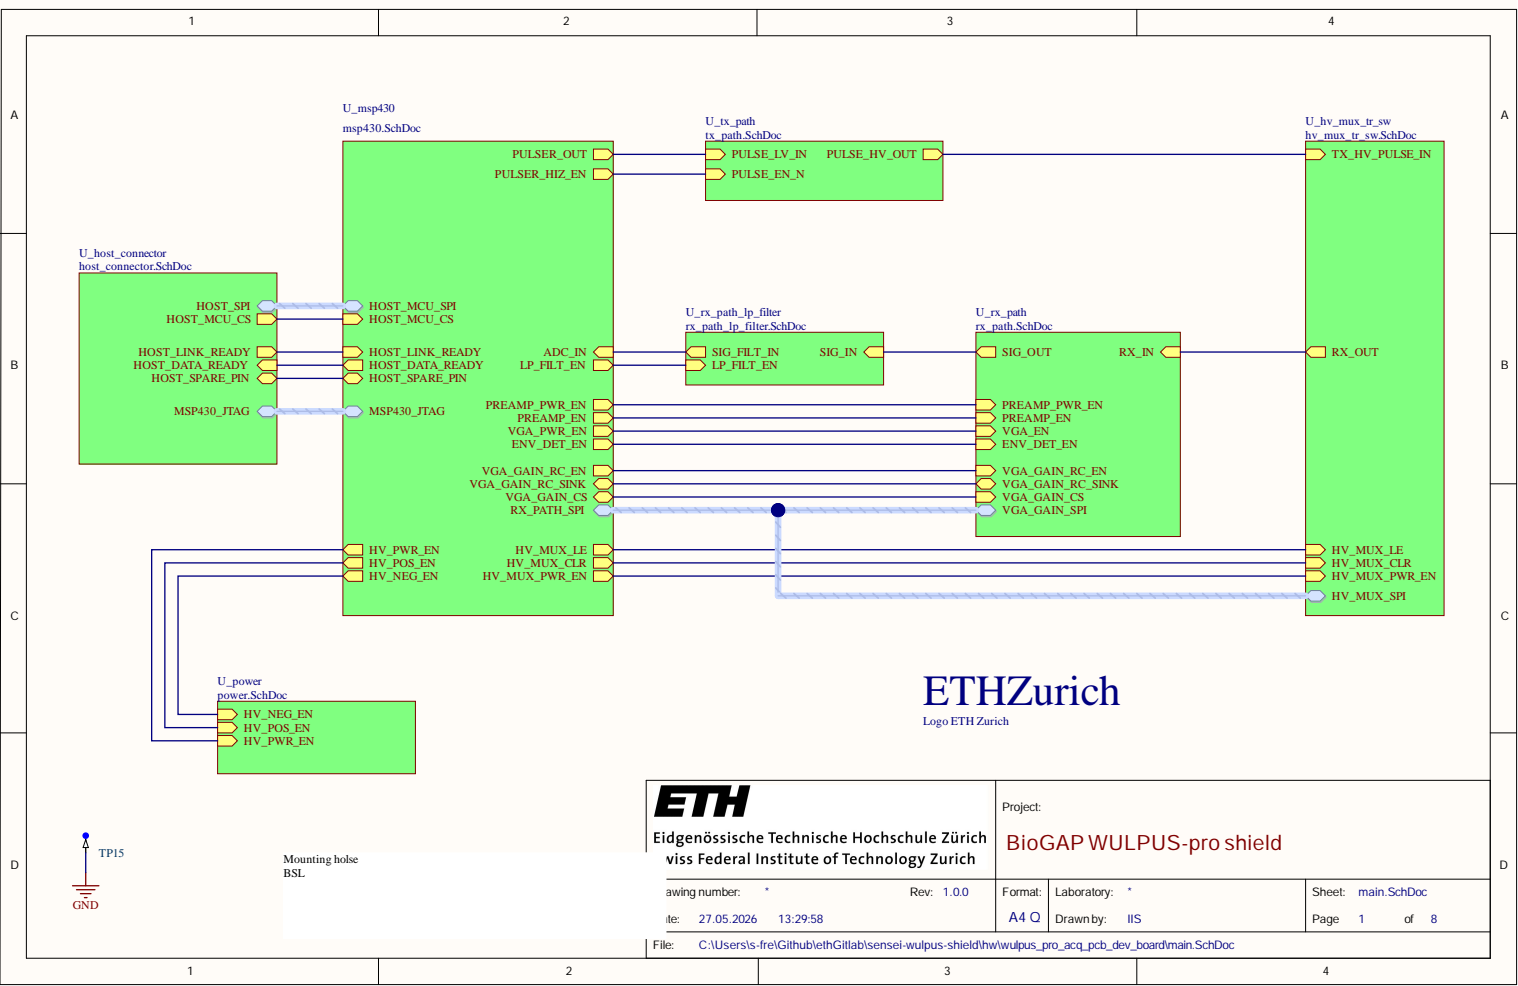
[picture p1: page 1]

Proje c t: B i o G A P W U L P U S -p ro s h i e l d

Drawing num D a | b e r: * R e v : 1. 0. 0 te : 27.05. 202 6 13:29 : 58 | Form a t: A 4 Q | Laborato ry : * Drawn by : I I S | Shee t: main. S c h D o c Pag e 1 of 8

\s-fre\Github\ethGitlab\sensei-wulpus-shield\hw\wu
sers

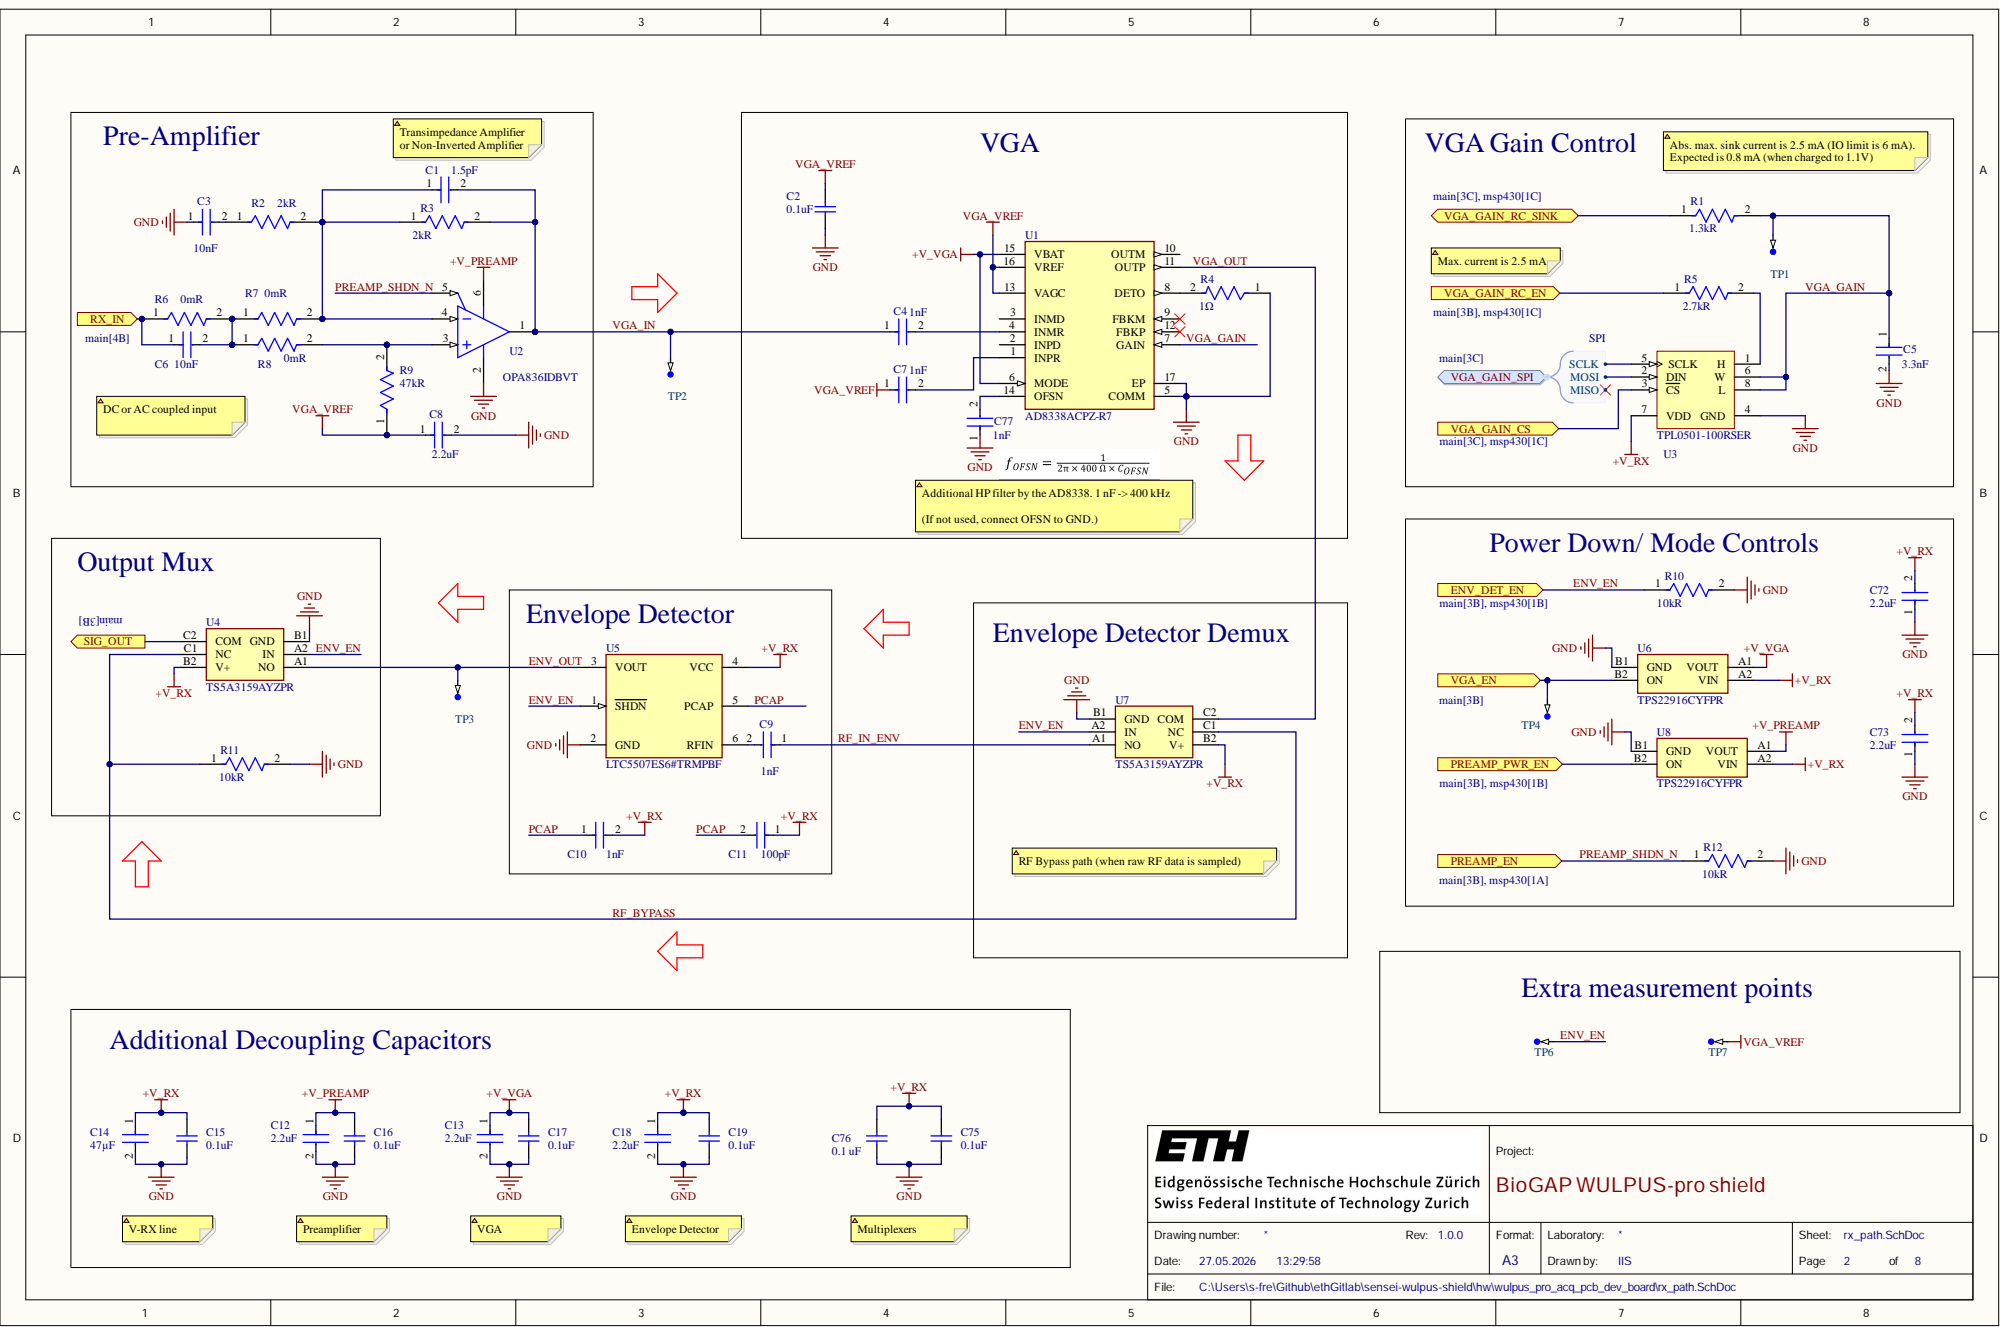
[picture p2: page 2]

Expected is 0.8 mA (when charged to 1.1V)

Max. current is 2.5 mA

MODE 6

DC or AC coupled input

VDD 7

Additional HP filter by the AD8338. 1 nF -> 400 kHz

(If not used, connect OFSN to GND.)

Power Down/ Mode Controls

RF Bypass path (when raw RF data is sampled)

Project: BioGAP WULPUS-pro shield

Drawing number: * Rev: 1.0.0 Date: 27.05.2026 13:29:58 | Format: A3 | Laboratory: * Drawn by: IIS | Sheet: rx_path.SchDoc Page 2 of 8

C:\Users\s-fre\Github\ethGitlab\sensei-wulpus-shield\hw\wulpus_pro_acq_pcb_dev_board\rx_path.SchDoc

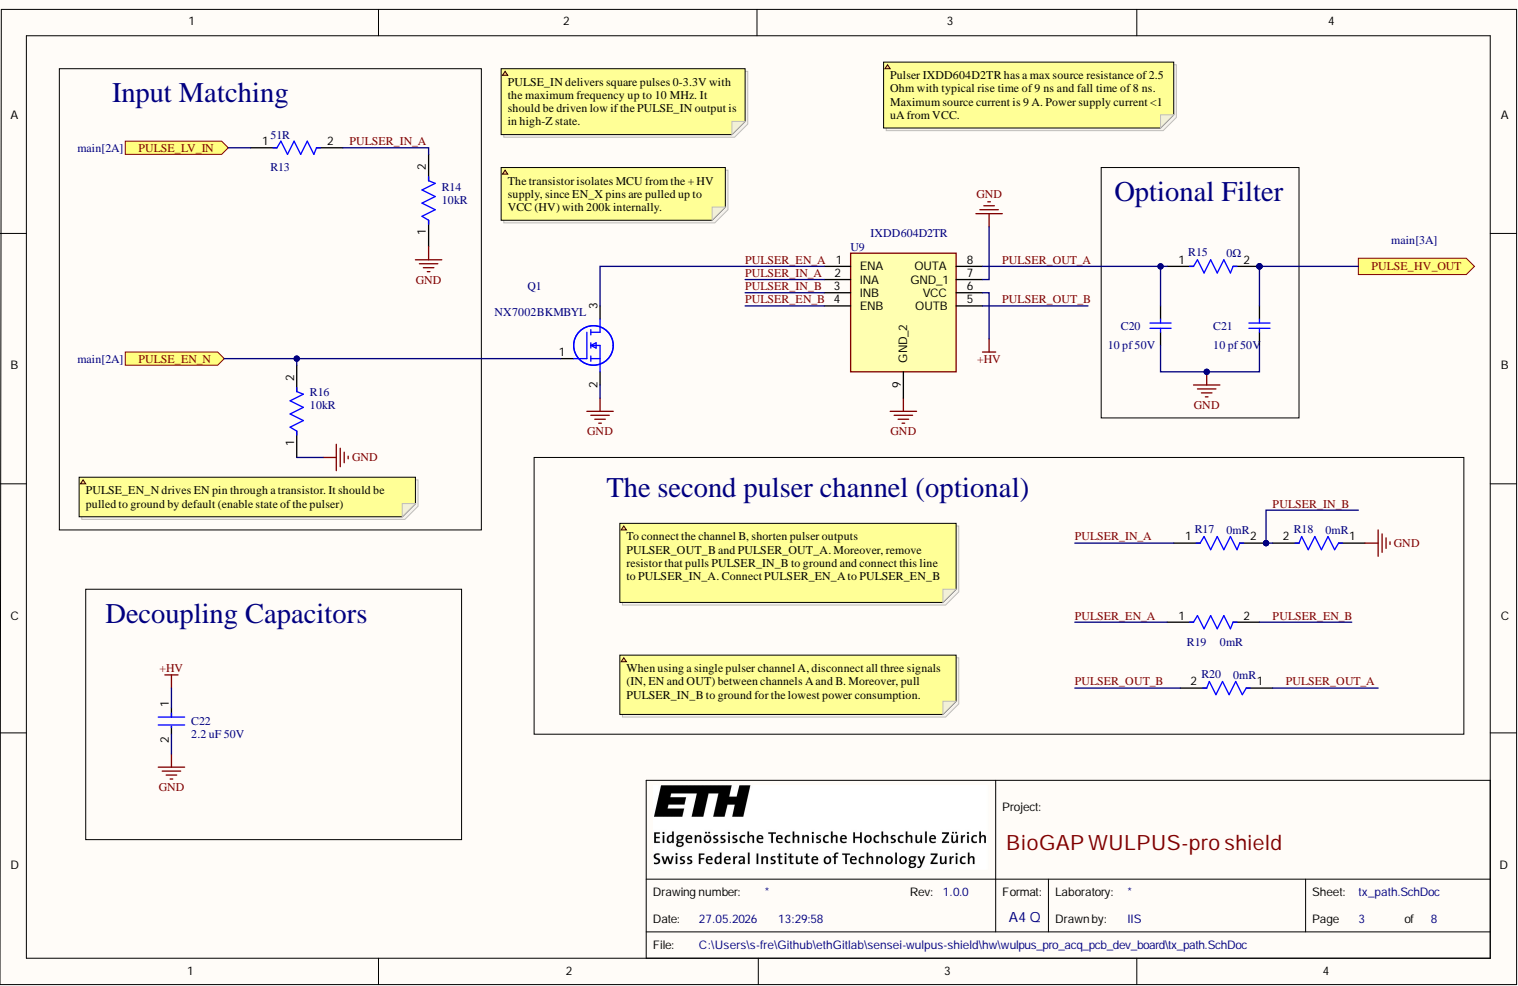
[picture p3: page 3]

PULSE_IN deliverssquare pulses 0-3.3V with
the maximum frequency up to 10 MHz. It
should be driven low if the PULSE_IN output is
in high-Z state.

Pulser IXDD604D2TR has a max source resistance of 2.5
Ohm with typical rise time of 9 ns and fall time of 8 ns.
Maximum source current is 9 A. Power supply current <1
uA from VCC.

The transistor isolates MCU from the + HV
supply, since EN_X pins are pulled up to
VCC (HV) with 200k internally.

PULSE_EN_N drives EN pin through a transistor. It should be
pulled to ground by default (enable state of the pulser)

The second pulser channel (optional)

To connect the channel B, shorten pulser outputs
PULSER_OUT_B and PULSER_OUT_A. Moreover, remove
resistor that pulls PULSER_IN_B to ground and connect this line
to PULSER_IN_A. Connect PULSER_EN_A to PULSER_EN_B

When using a single pulser channel A, disconnect all three signals
(IN, EN and OUT) between channels A and B. Moreover, pull
PULSER_IN_B to ground for the lowest power consumption.

Project: BioGAP WULPUS-pro shield

Drawing number: * Rev: 1.0.0 | Format: A4 Q | Laboratory: * | Sheet: tx_path.SchDoc Page 3 of 8

C:\Users\s-fre\Github\ethGitlab\sensei-wulpus-shield\hw\wulpus_pro_acq_pcb_dev_board\tx_path.SchDoc

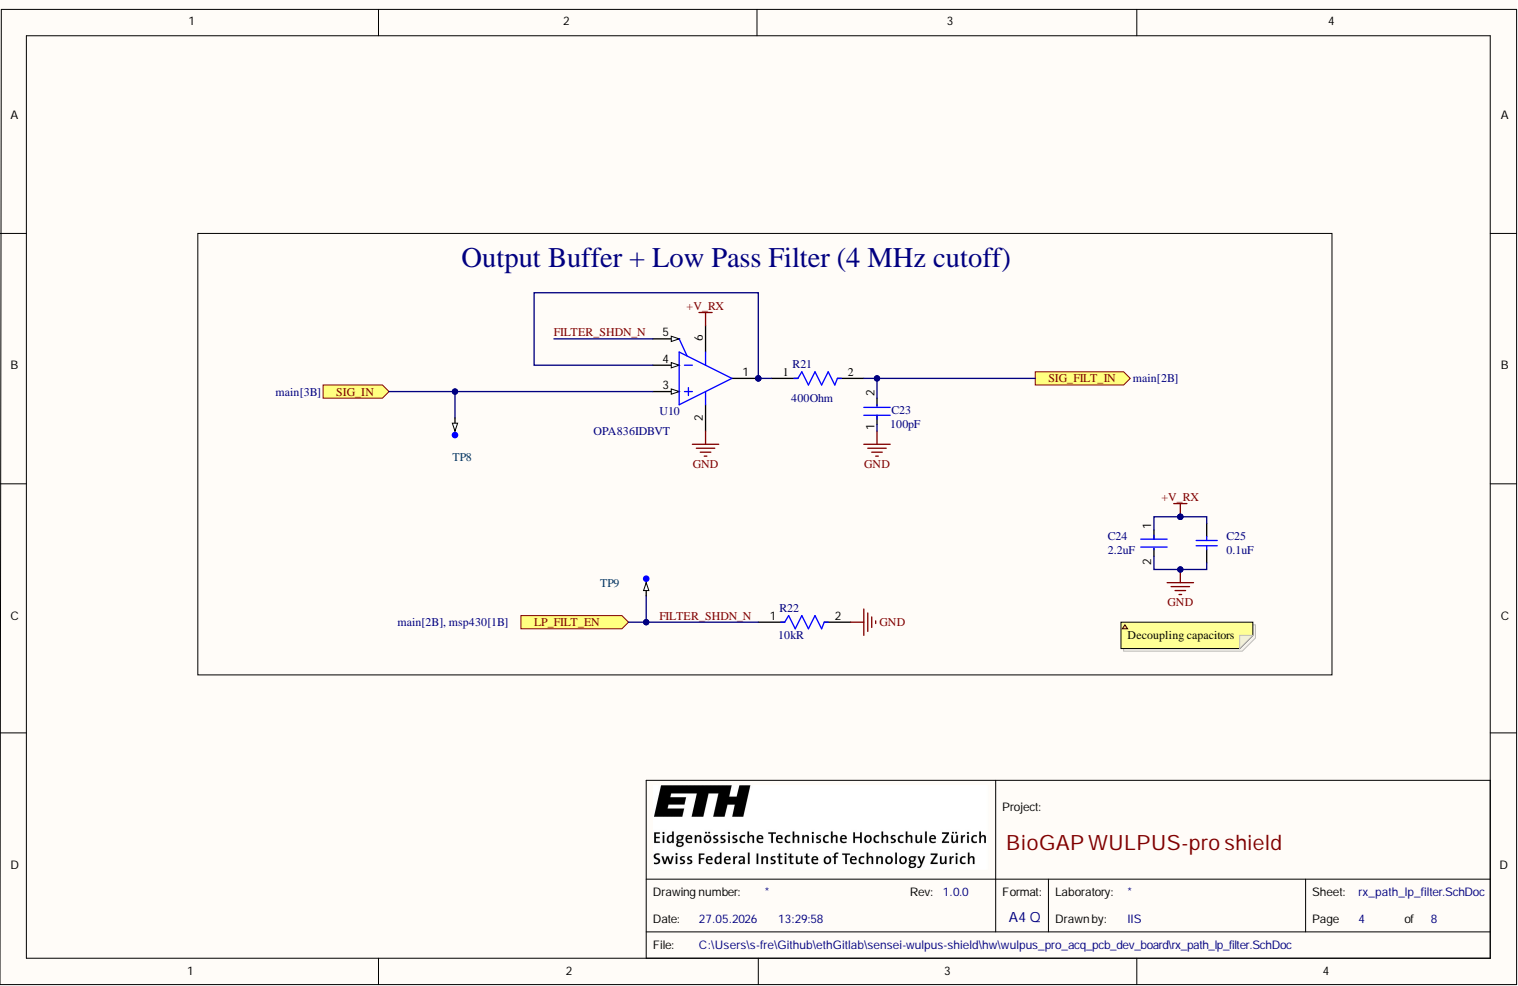
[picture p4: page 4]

Output Buffer + Low Pass Filter (4 MHz cutoff)

Project: BioGAP WULPUS-pro shield

Drawing number: * Rev: 1.0.0 | Format: A4 Q | Laboratory: * | Sheet: rx_path_lp_filter.SchDoc Page 4 of 8

C:\Users\s-fre\Github\ethGitlab\sensei-wulpus-shield\hw\wulpus_pro_acq_pcb_dev_board\rx_path_lp_filter.SchDoc

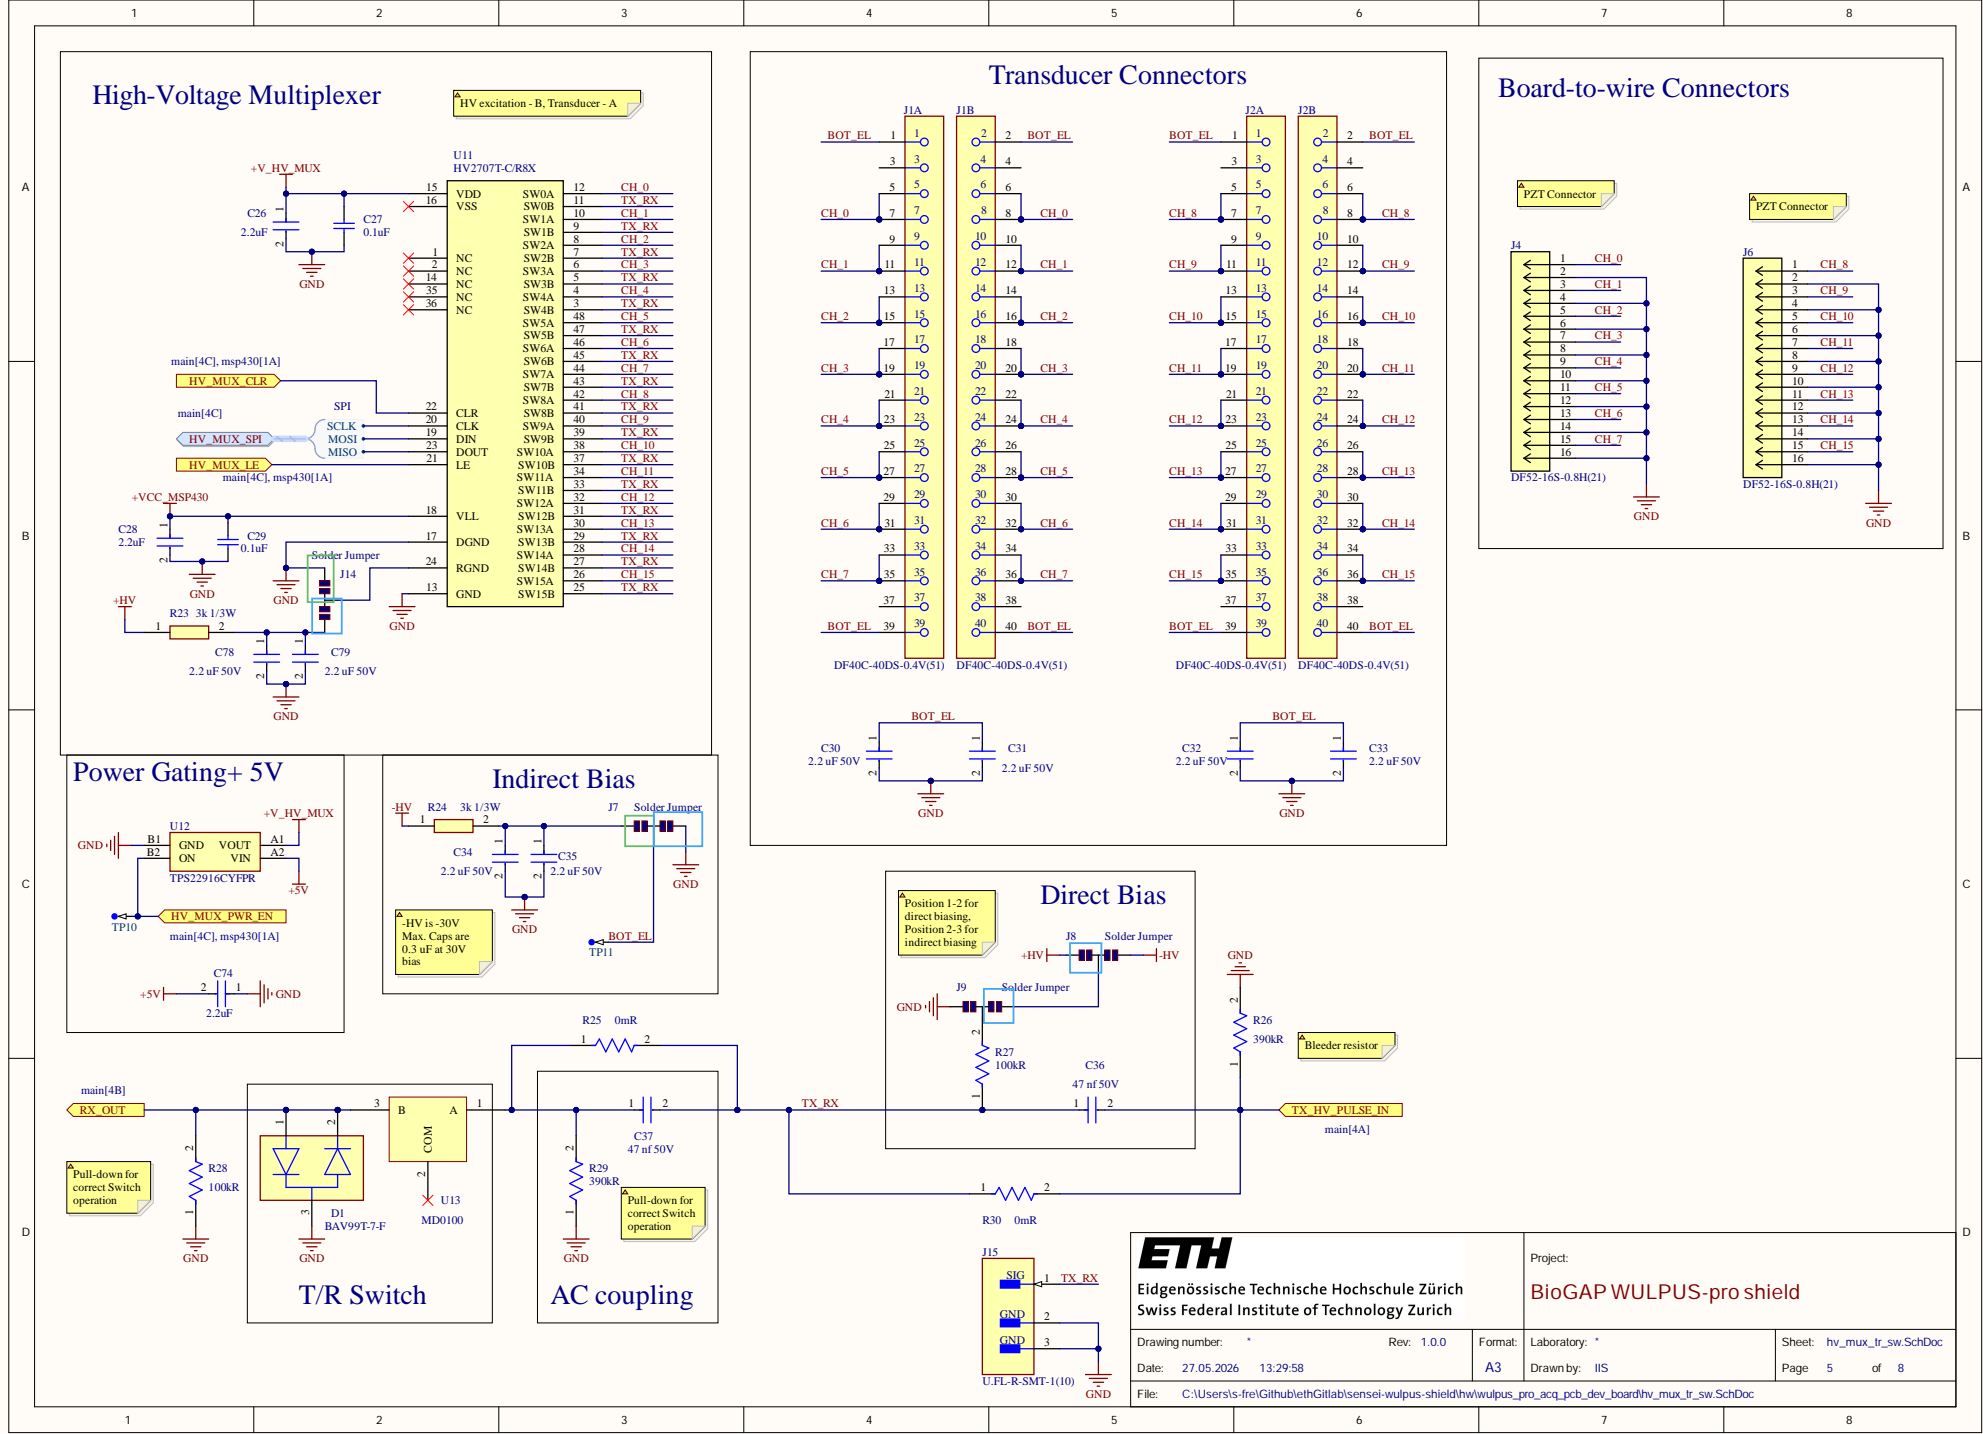
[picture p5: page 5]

Project:
BioGAP WULPUS-pro shield

C:\Users\s-fre\Github\ethGitlab\sensei-wulpus-shield\hw\wulpus_pro_acq_pcb_dev_board\hv_mux_tr_sw.SchDoc

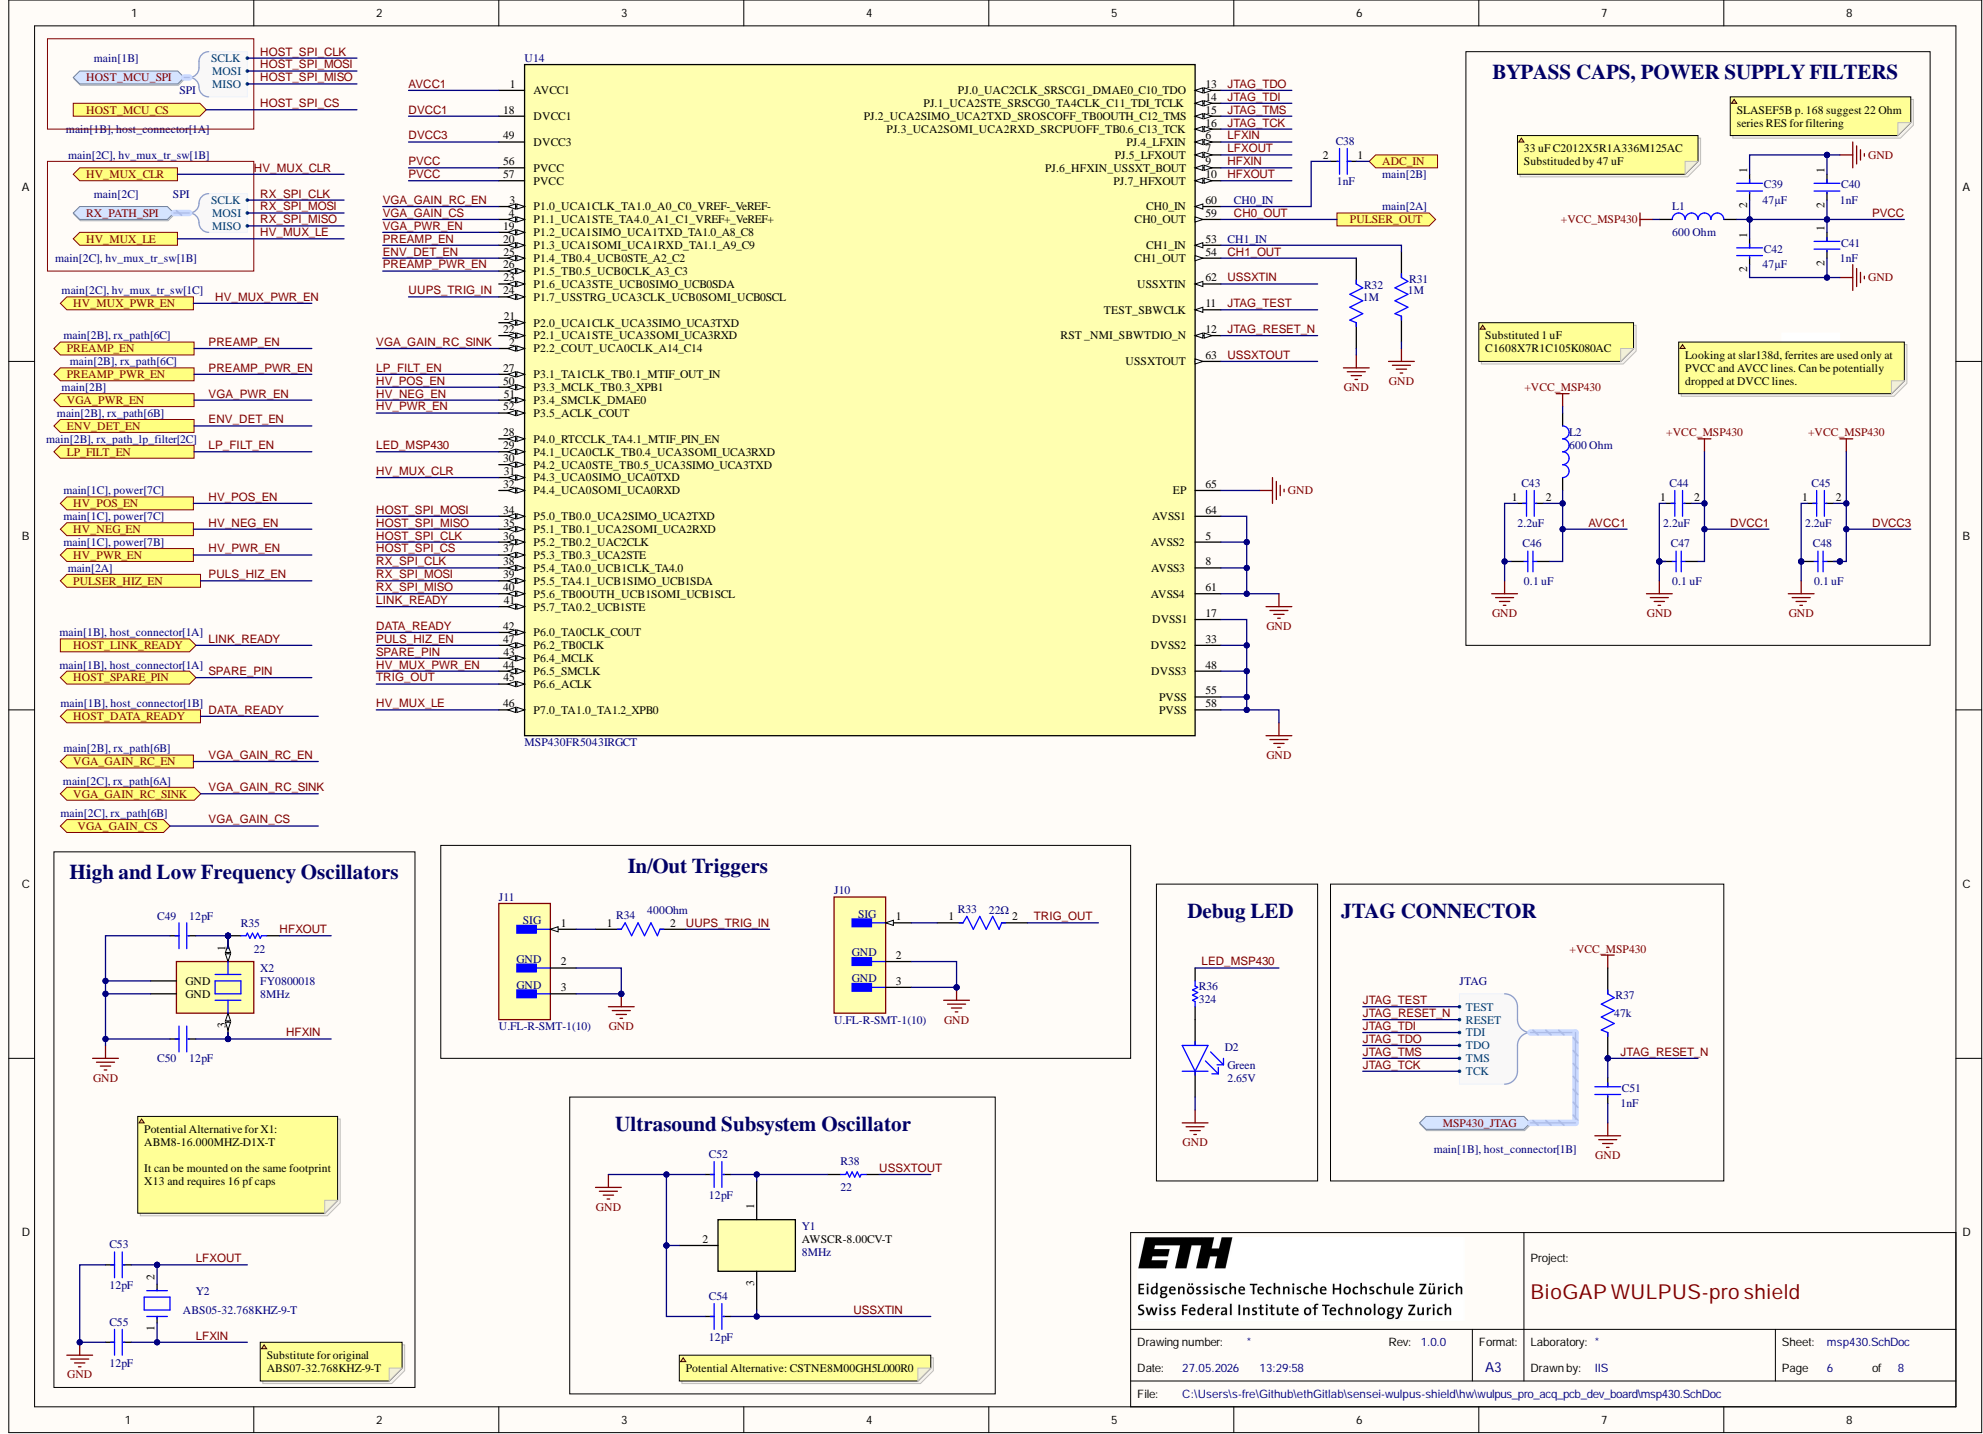
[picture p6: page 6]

BYPASS CAPS, POWER SUPPLY FILTERS

SLASEF5B p. 168 suggest 22 Ohm
series RES for filtering

PVCC and AVCC lines. Can be potentially
dropped at DVCC lines.

High and Low Frequency Oscillators

It can be mounted on the same footprint
X13 and requires 16 pf caps

Project: BioGAP WULPUS-pro shield

msp430.SchDoc Page 6 of 8

C:\Users\s-fre\Github\ethGitlab\sensei-wulpus-shield\hw\wulpus_pro_acq_pcb_dev_board\msp430.SchDoc

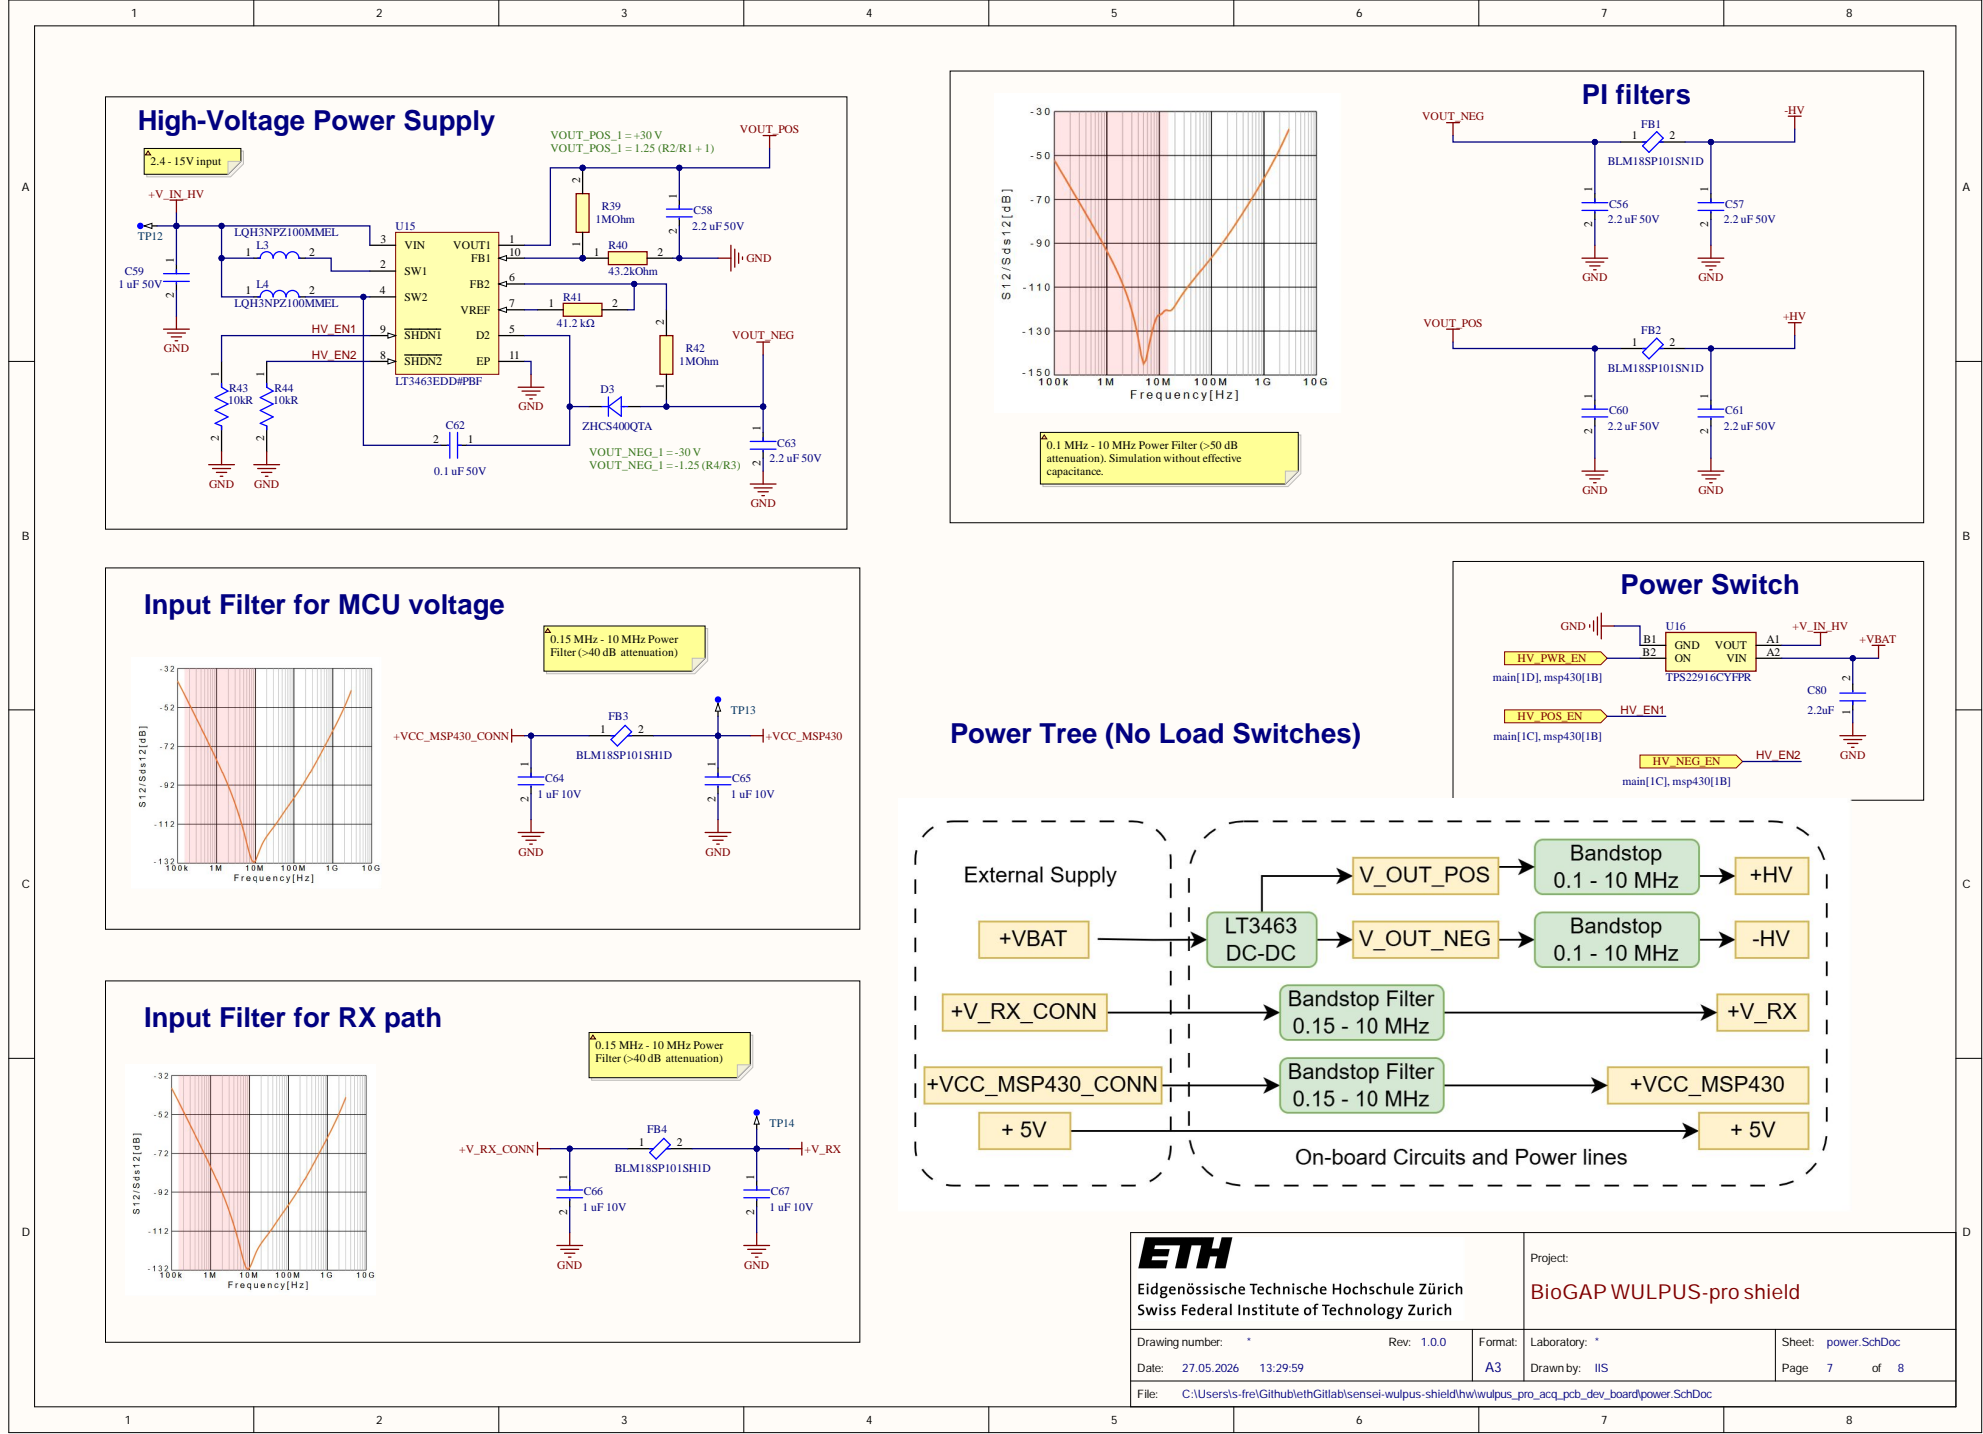
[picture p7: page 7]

High-Voltage Power Supply

SHDN1 9

0.1 MHz - 10 MHz Power Filter (>50 dB
attenuation). Simulation without effective
capacitance.

Input Filter for MCU voltage

Input Filter for RX path

Project: BioGAP WULPUS-pro shield

power.SchDoc Page 7 of 8

C:\Users\s-fre\Github\ethGitlab\sensei-wulpus-shield\hw\wulpus_pro_acq_pcb_dev_board\power.SchDoc

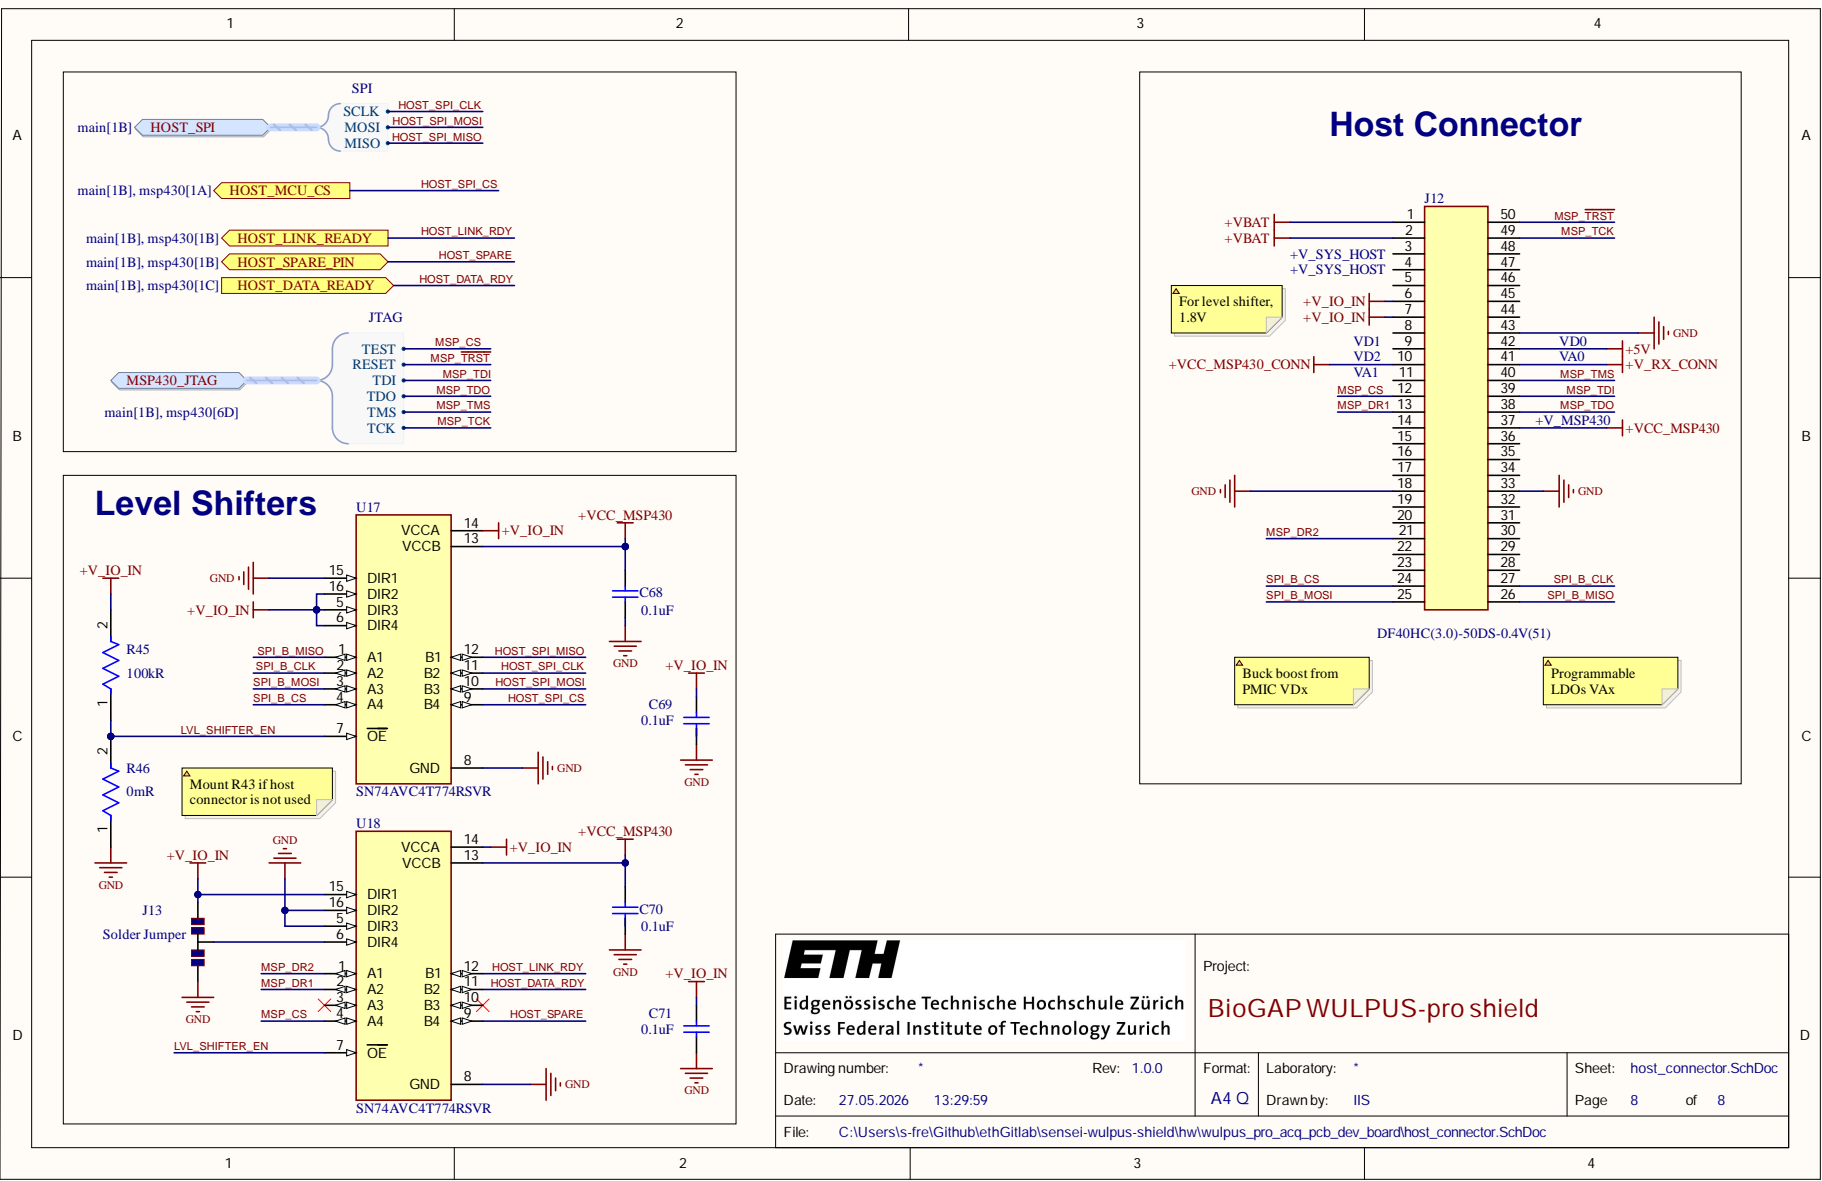
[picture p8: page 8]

1 6

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

Drawing num b e r: * R e v : 1. 0. 0 D a te : 27.05. 202 6 13:29 : 59 | Form a t: A 4 Q | Laborato ry : * Drawn by : I I S | Shee t: hos t_connec to r. S c h D o c Pag e 8 of 8

\s-fre\Github\ethGitlab\sensei-wulpus-shield\hw\wulpus
sers

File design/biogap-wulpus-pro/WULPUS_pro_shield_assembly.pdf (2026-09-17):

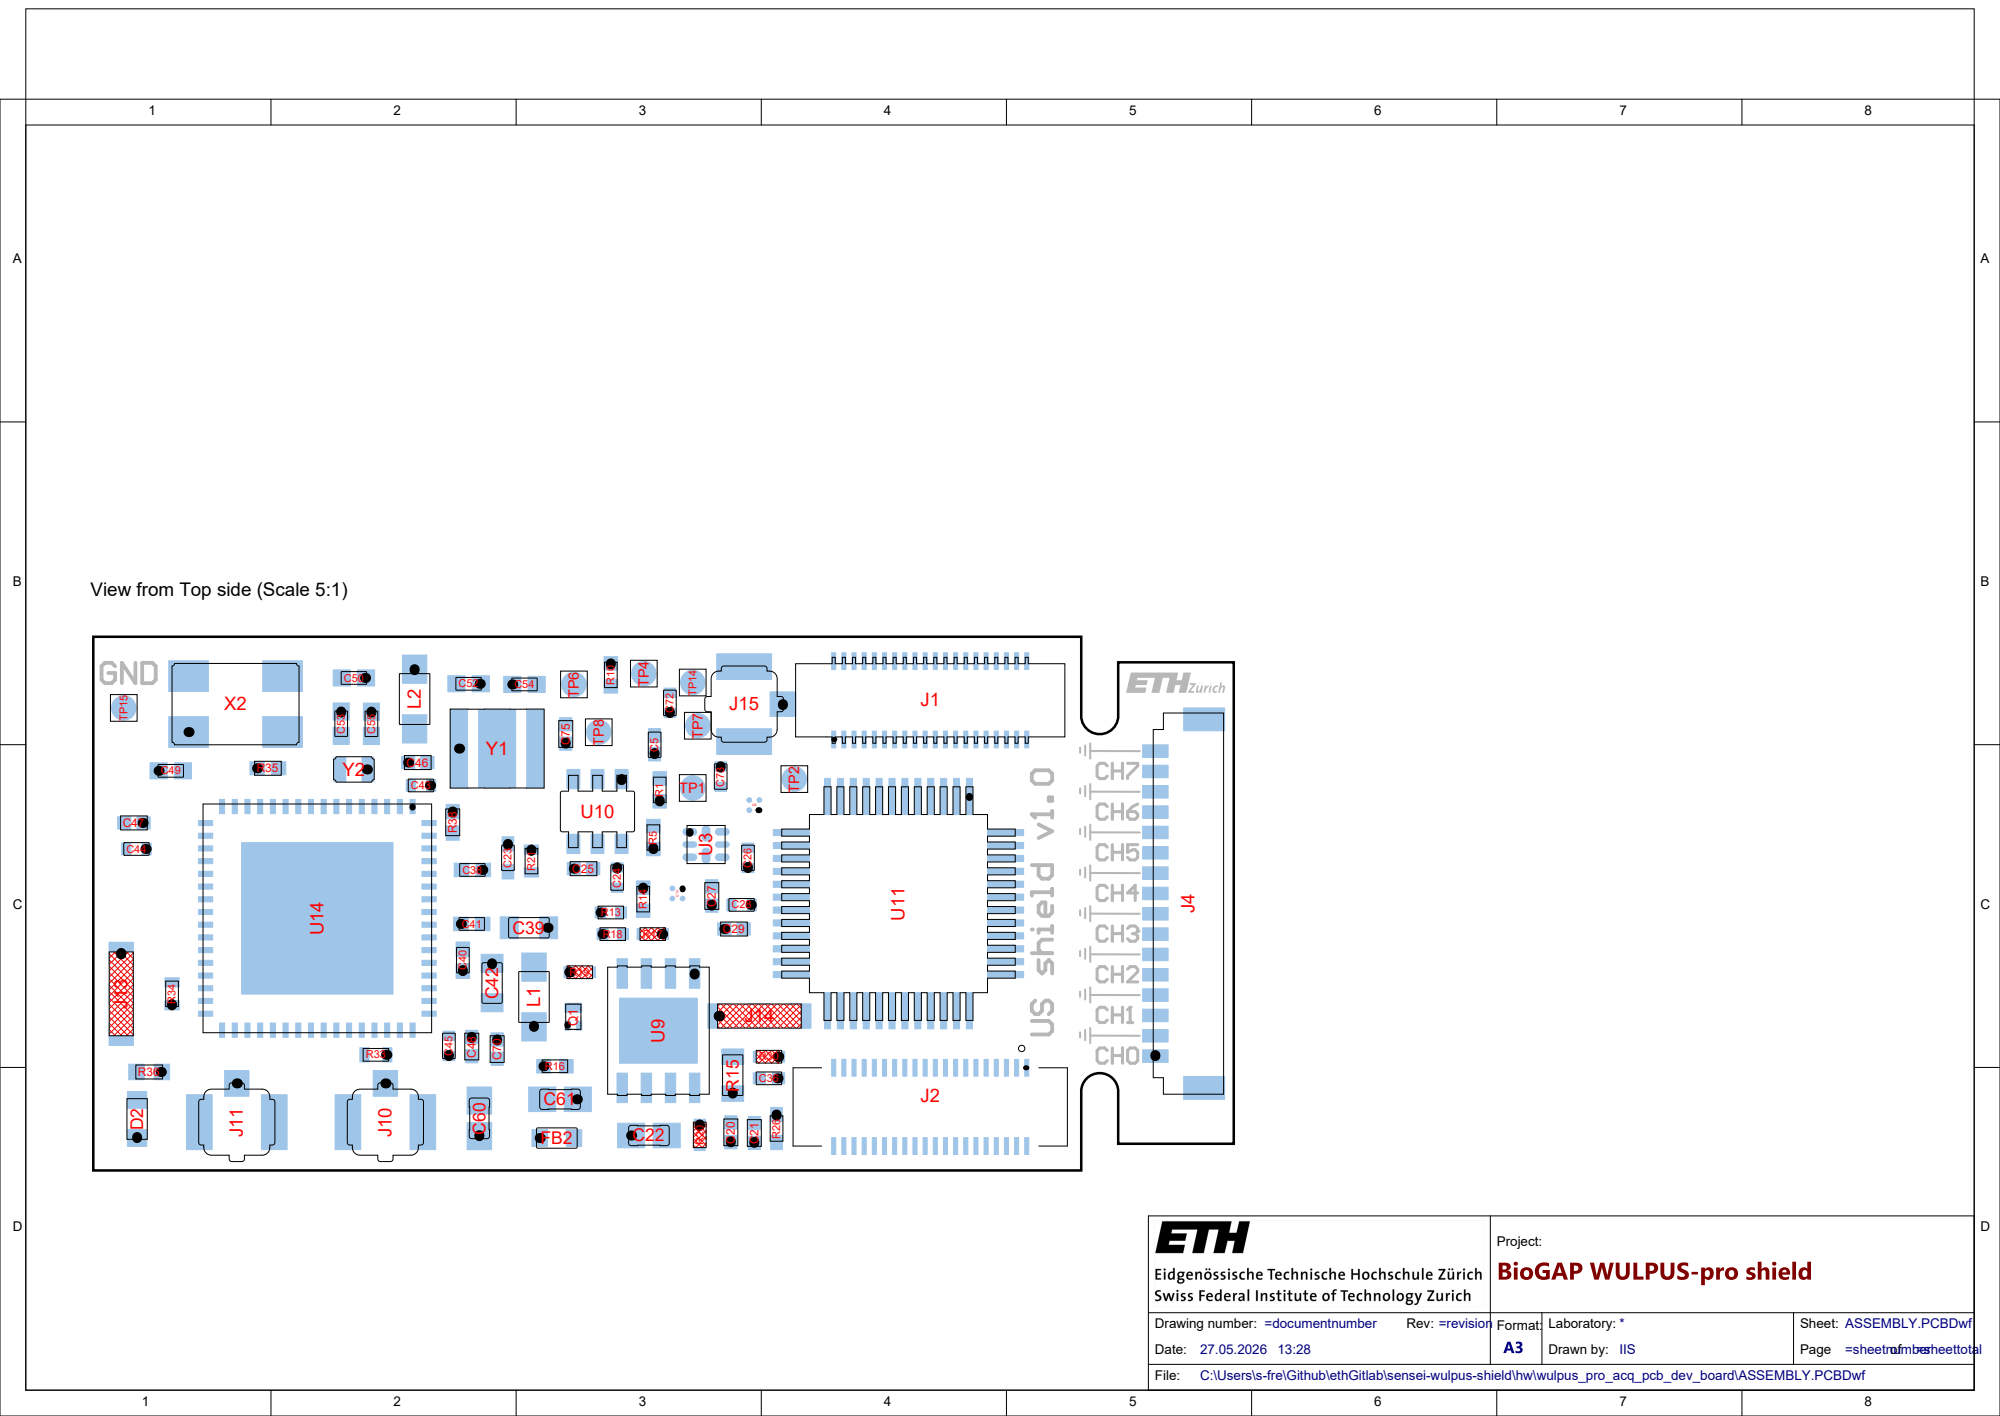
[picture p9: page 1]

View from Top side (Scale 5:1)

Project:

Drawing number: =documentnumber Rev: =revision Format: Date: 27.05.2026 13:28 | | Laboratory: * Drawn by: IIS | Sheet: ASSEMBLY.PCBDwf

Page =sheetnumber of =sheettotal

C:\Users\s-fre\Github\ethGitlab\sensei-wulpus-shield\hw\wulpus_pro_acq_pcb_dev_board\ASSEMBLY.PCBDwf

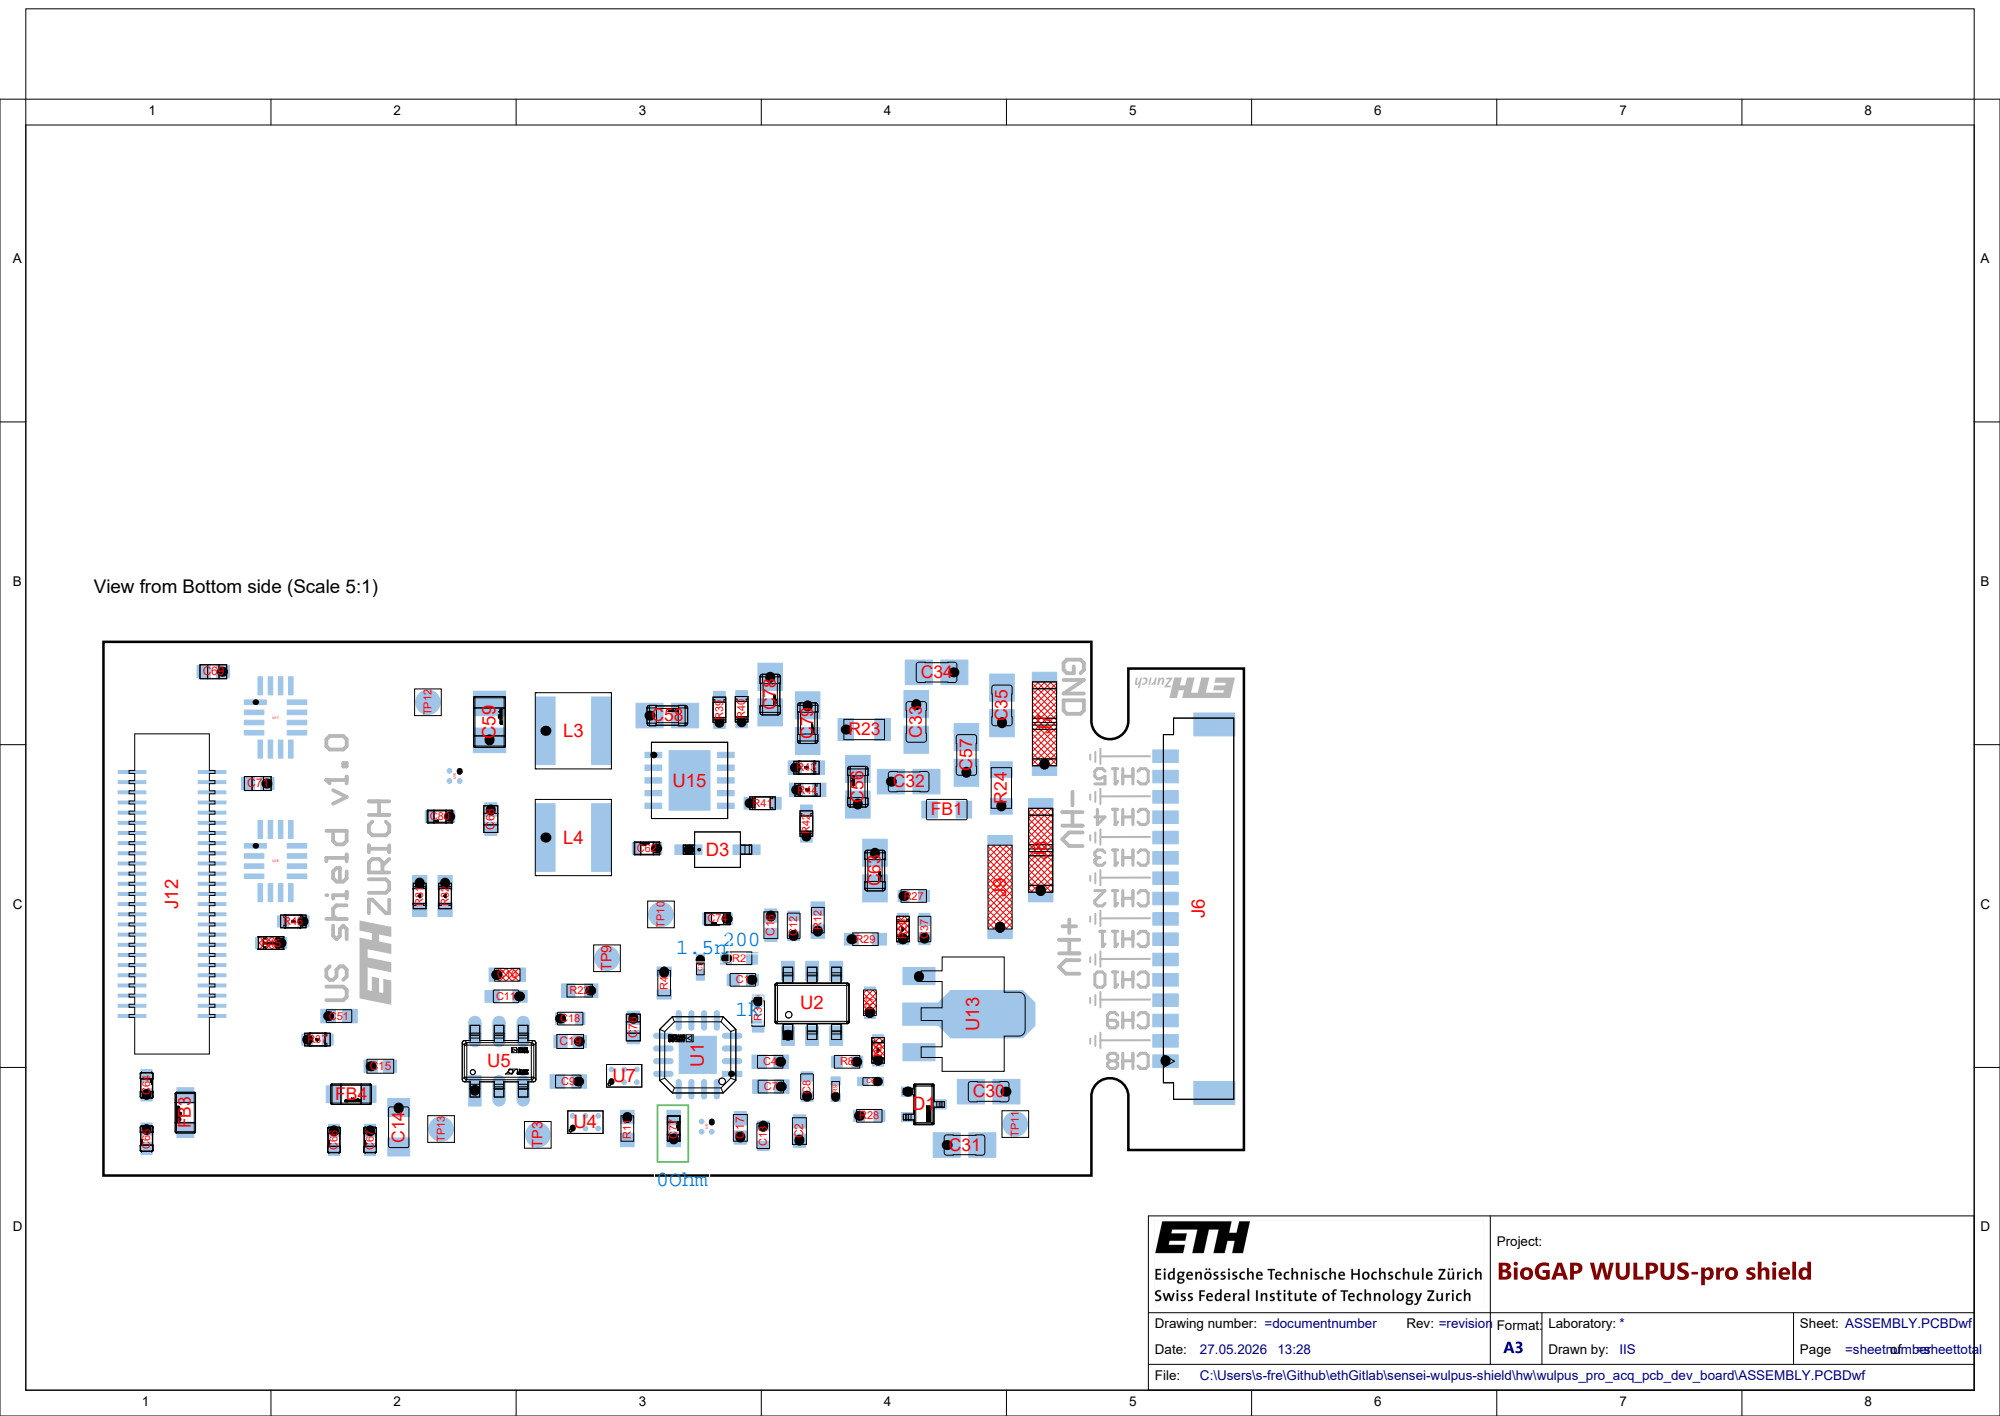
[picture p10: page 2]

View from Bottom side (Scale 5:1)

Sheet:
Page =sheetnumber of =sheettotal

C:\Users\s-fre\Github\ethGitlab\sensei-wulpus-shield\hw\wulpus_pro_acq_pcb_dev_board\ASSEMBLY.PCBDwf

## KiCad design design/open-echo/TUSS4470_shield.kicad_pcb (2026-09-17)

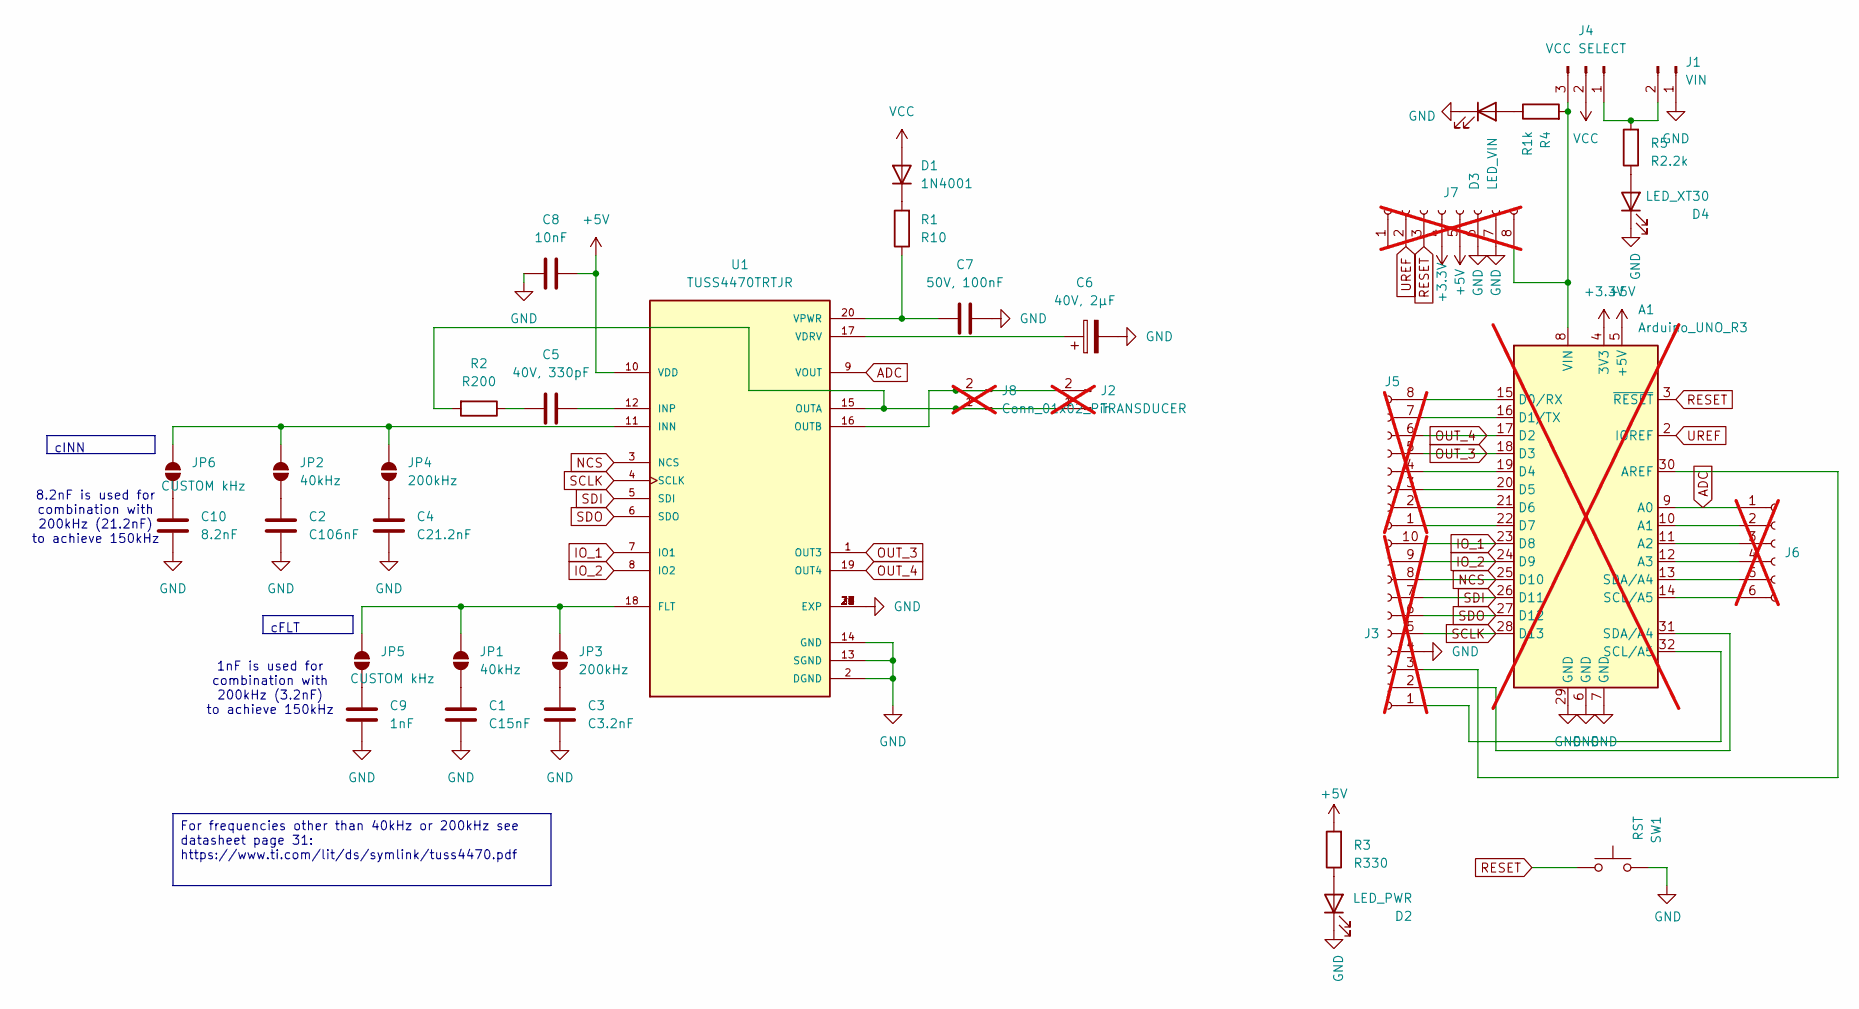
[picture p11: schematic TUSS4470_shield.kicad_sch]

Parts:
A1: Arduino_UNO_R3; not fitted
C1: C15nF; C_0603_1608Metric; LCSC C1596
C2: C106nF; C_0603_1608Metric; LCSC C14663
C3: C3.2nF; C_0603_1608Metric; LCSC C1613
C4: C21.2nF; C_0603_1608Metric; LCSC C1602
C5: 40V, 330pF; C_0603_1608Metric; LCSC C1664
C6: 40V, 2µF; C_1206_3216Metric; LCSC C50254
C7: 50V, 100nF; C_0603_1608Metric; LCSC C14663
C8: 10nF; C_0603_1608Metric; LCSC C57112
C9: 1nF; C_0603_1608Metric; LCSC C1588
C10: 8.2nF; C_0603_1608Metric; LCSC C1322360
D1: 1N4001; D_SMA; LCSC C727079
D2: LED_PWR; LED_0805_2012Metric; LCSC C84256
D3: LED_VIN; LED_0805_2012Metric; LCSC C84256
D4: LED_XT30; LED_0805_2012Metric; LCSC C84256
J1: VIN; AMASS_XT30PW-M_1x02_P2.50mm_Horizontal; LCSC C431092
J2: TRANSDUCER; TerminalBlock_4Ucon_1x02_P3.50mm_Horizontal; not fitted
J3: Conn_01x10_Socket; PinHeader_1x10_P2.54mm_Vertical; not fitted
J4: VCC SELECT; PinHeader_1x03_P2.54mm_Vertical; LCSC C49257
J5, J7: Conn_01x08_Socket; PinHeader_1x08_P2.54mm_Vertical; not fitted
J6: Conn_01x06_Socket; PinHeader_1x06_P2.54mm_Vertical; not fitted
J8: Conn_01x02_Pin; PinHeader_1x02_P2.54mm_Vertical; not fitted
JP1, JP2: 40kHz; PinHeader_1x02_P2.54mm_Vertical; LCSC C2905434
JP3, JP4: 200kHz; PinHeader_1x02_P2.54mm_Vertical; LCSC C2905434
JP5, JP6: CUSTOM kHz; PinHeader_1x02_P2.54mm_Vertical; LCSC C2905434
R1: R10; R_1206_3216Metric; LCSC C17903
R2: R200; R_1206_3216Metric; LCSC C18002
R3: R330; R_0603_1608Metric; LCSC C23138
R4: R1k; R_0603_1608Metric; LCSC C14676
R5: R2.2k; R_0603_1608Metric; LCSC C4190
SW1: RST; SW_Push_1P1T_NO_CK_KSC7xxJ; LCSC C318884
U1: TUSS4470TRTJR; QFN-20-1EP_4x4mm_P0.5mm_EP2.5x2.5mm_ThermalVias; PARTREV December 2019; LCSC C1855776

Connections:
+3.3V: A1.4 (3V3), J7.4
+5V: A1.5 (+5V), C8.2, J7.5, R3.2, U1.10 (VDD)
ADC: A1.9 (A0), J6.1, U1.9 (VOUT)
GND: A1.6 (GND), A1.7 (GND), A1.29 (GND), C1.2, C2.2, C3.2, C4.2, C6.2, C7.2, C8.1, C9.2, C10.2, D2.1 (K), D3.1 (K), D4.1 (K), J1.1, J3.4, J7.6, J7.7, SW1.2, U1.2 (DGND), U1.13 (SGND), U1.14 (GND), U1.21 (EXP), U1.22 (EXP), U1.23 (EXP), U1.24 (EXP), U1.25 (EXP), U1.26 (EXP), U1.27 (EXP), U1.28 (EXP), U1.29 (EXP), U1.30 (EXP)
IO_1: A1.23 (D8), J3.10, U1.7 (IO1)
IO_2: A1.24 (D9), J3.9, U1.8 (IO2)
NCS: A1.25 (D10), J3.8, U1.3 (NCS)
unnamed: A1.10 (A1), J6.2
unnamed: A1.11 (A2), J6.3
unnamed: A1.12 (A3), J6.4
unnamed: A1.30 (AREF), J3.3
unnamed: A1.15 (D0/RX), J5.8
unnamed: A1.16 (D1/TX), J5.7
unnamed: A1.19 (D4), J5.4
unnamed: A1.20 (D5), J5.3
unnamed: A1.21 (D6), J5.2
unnamed: A1.22 (D7), J5.1
unnamed: A1.8 (VIN), J4.3, J7.8, R4.2
unnamed: C5.1, R2.1
unnamed: D1.1 (K), R1.2
unnamed: D2.2 (A), R3.1
unnamed: D3.2 (A), R4.1
unnamed: D4.2 (A), R5.1
unnamed: J1.2, J4.1, R5.2
unnamed: J2.1, J8.1, R2.2, U1.15 (OUTA)
unnamed: J2.2, J8.2, U1.16 (OUTB)
unnamed: A1.32 (SCL/A5), J3.1
unnamed: A1.31 (SDA/A4), J3.2
unnamed: A1.13 (SDA/A4), J6.5
unnamed: A1.14 (SCL/A5), J6.6
unnamed: C1.1, JP1.1 (A)
unnamed: JP1.2 (B), JP3.2 (B), JP5.2 (B), U1.18 (FLT)
unnamed: C2.1, JP2.1 (A)
unnamed: JP2.2 (B), JP4.2 (B), JP6.2 (B), U1.11 (INN)
unnamed: C3.1, JP3.1 (A)
unnamed: C4.1, JP4.1 (A)
unnamed: C9.1, JP5.1 (A)
unnamed: C10.1, JP6.1 (A)
unnamed: C5.2, U1.12 (INP)
unnamed: C6.1, U1.17 (VDRV)
unnamed: C7.1, R1.1, U1.20 (VPWR)
OUT_3: A1.18 (D3), J5.5, U1.1 (OUT3)
OUT_4: A1.17 (D2), J5.6, U1.19 (OUT4)
RESET: A1.3 (~RESET), J7.3, SW1.1
SCLK: A1.28 (D13), J3.5, U1.4 (SCLK)
SDI: A1.26 (D11), J3.7, U1.5 (SDI)
SDO: A1.27 (D12), J3.6, U1.6 (SDO)
UREF: A1.2 (IOREF), J7.2
VCC: D1.2 (A), J4.2

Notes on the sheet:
8.2nF is used for combination with 200kHz (21.2nF) to achieve 150kHz
1nF is used for combination with 200kHz (3.2nF) to achieve 150kHz
cFLT
For frequencies other than 40kHz or 200kHz see datasheet page 31: https://www.ti.com/lit/ds/symlink/tuss4470.pdf
cINN

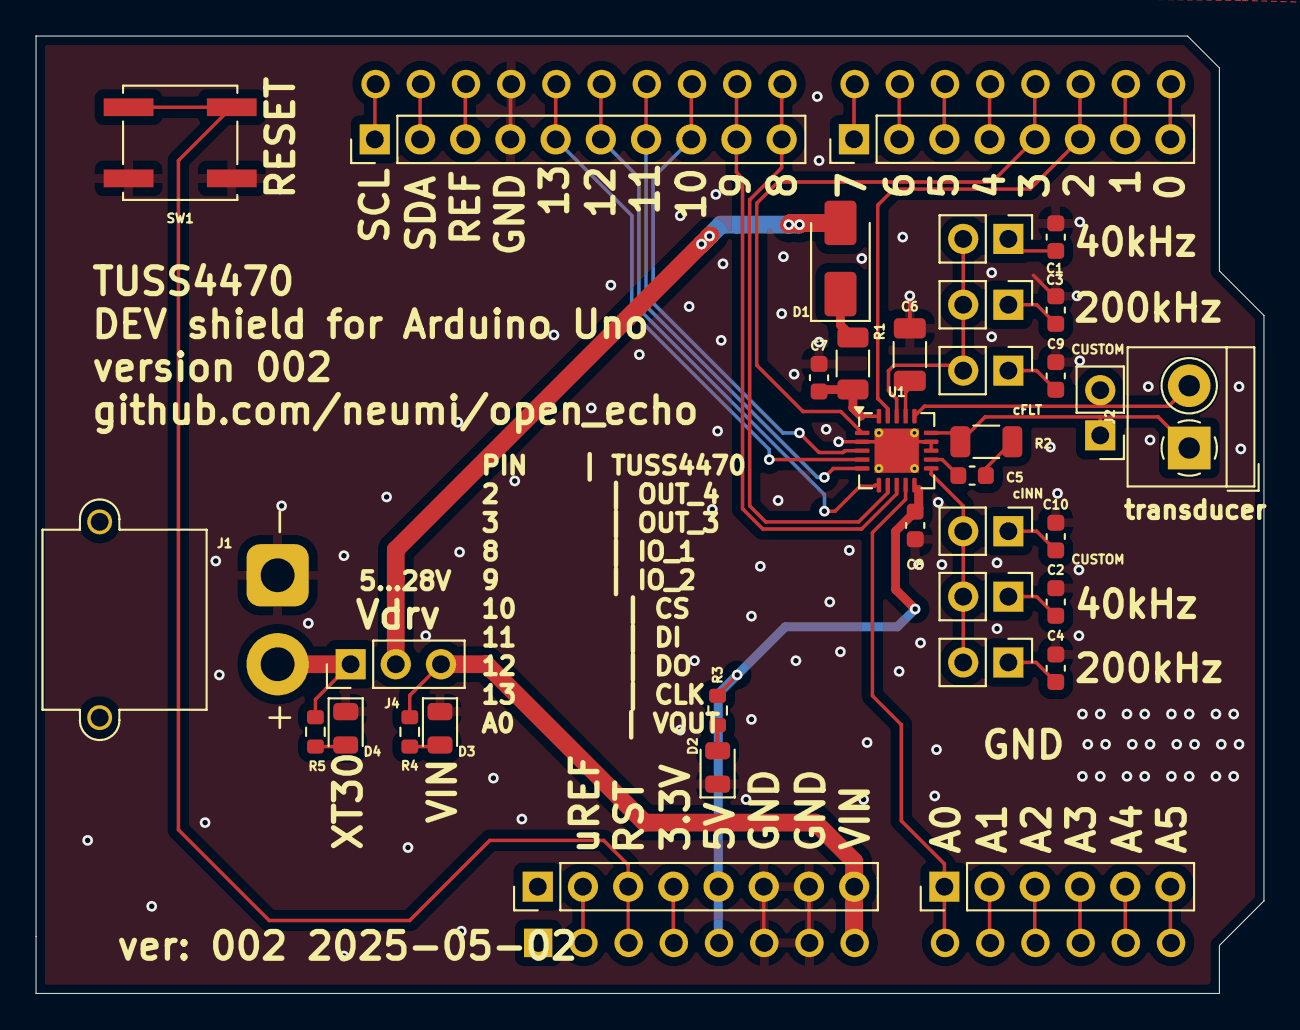
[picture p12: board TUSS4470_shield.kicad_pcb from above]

Board: 2 copper layers, 69.0 x 53.8 mm, 36 parts (1 on the bottom side), 49 nets.

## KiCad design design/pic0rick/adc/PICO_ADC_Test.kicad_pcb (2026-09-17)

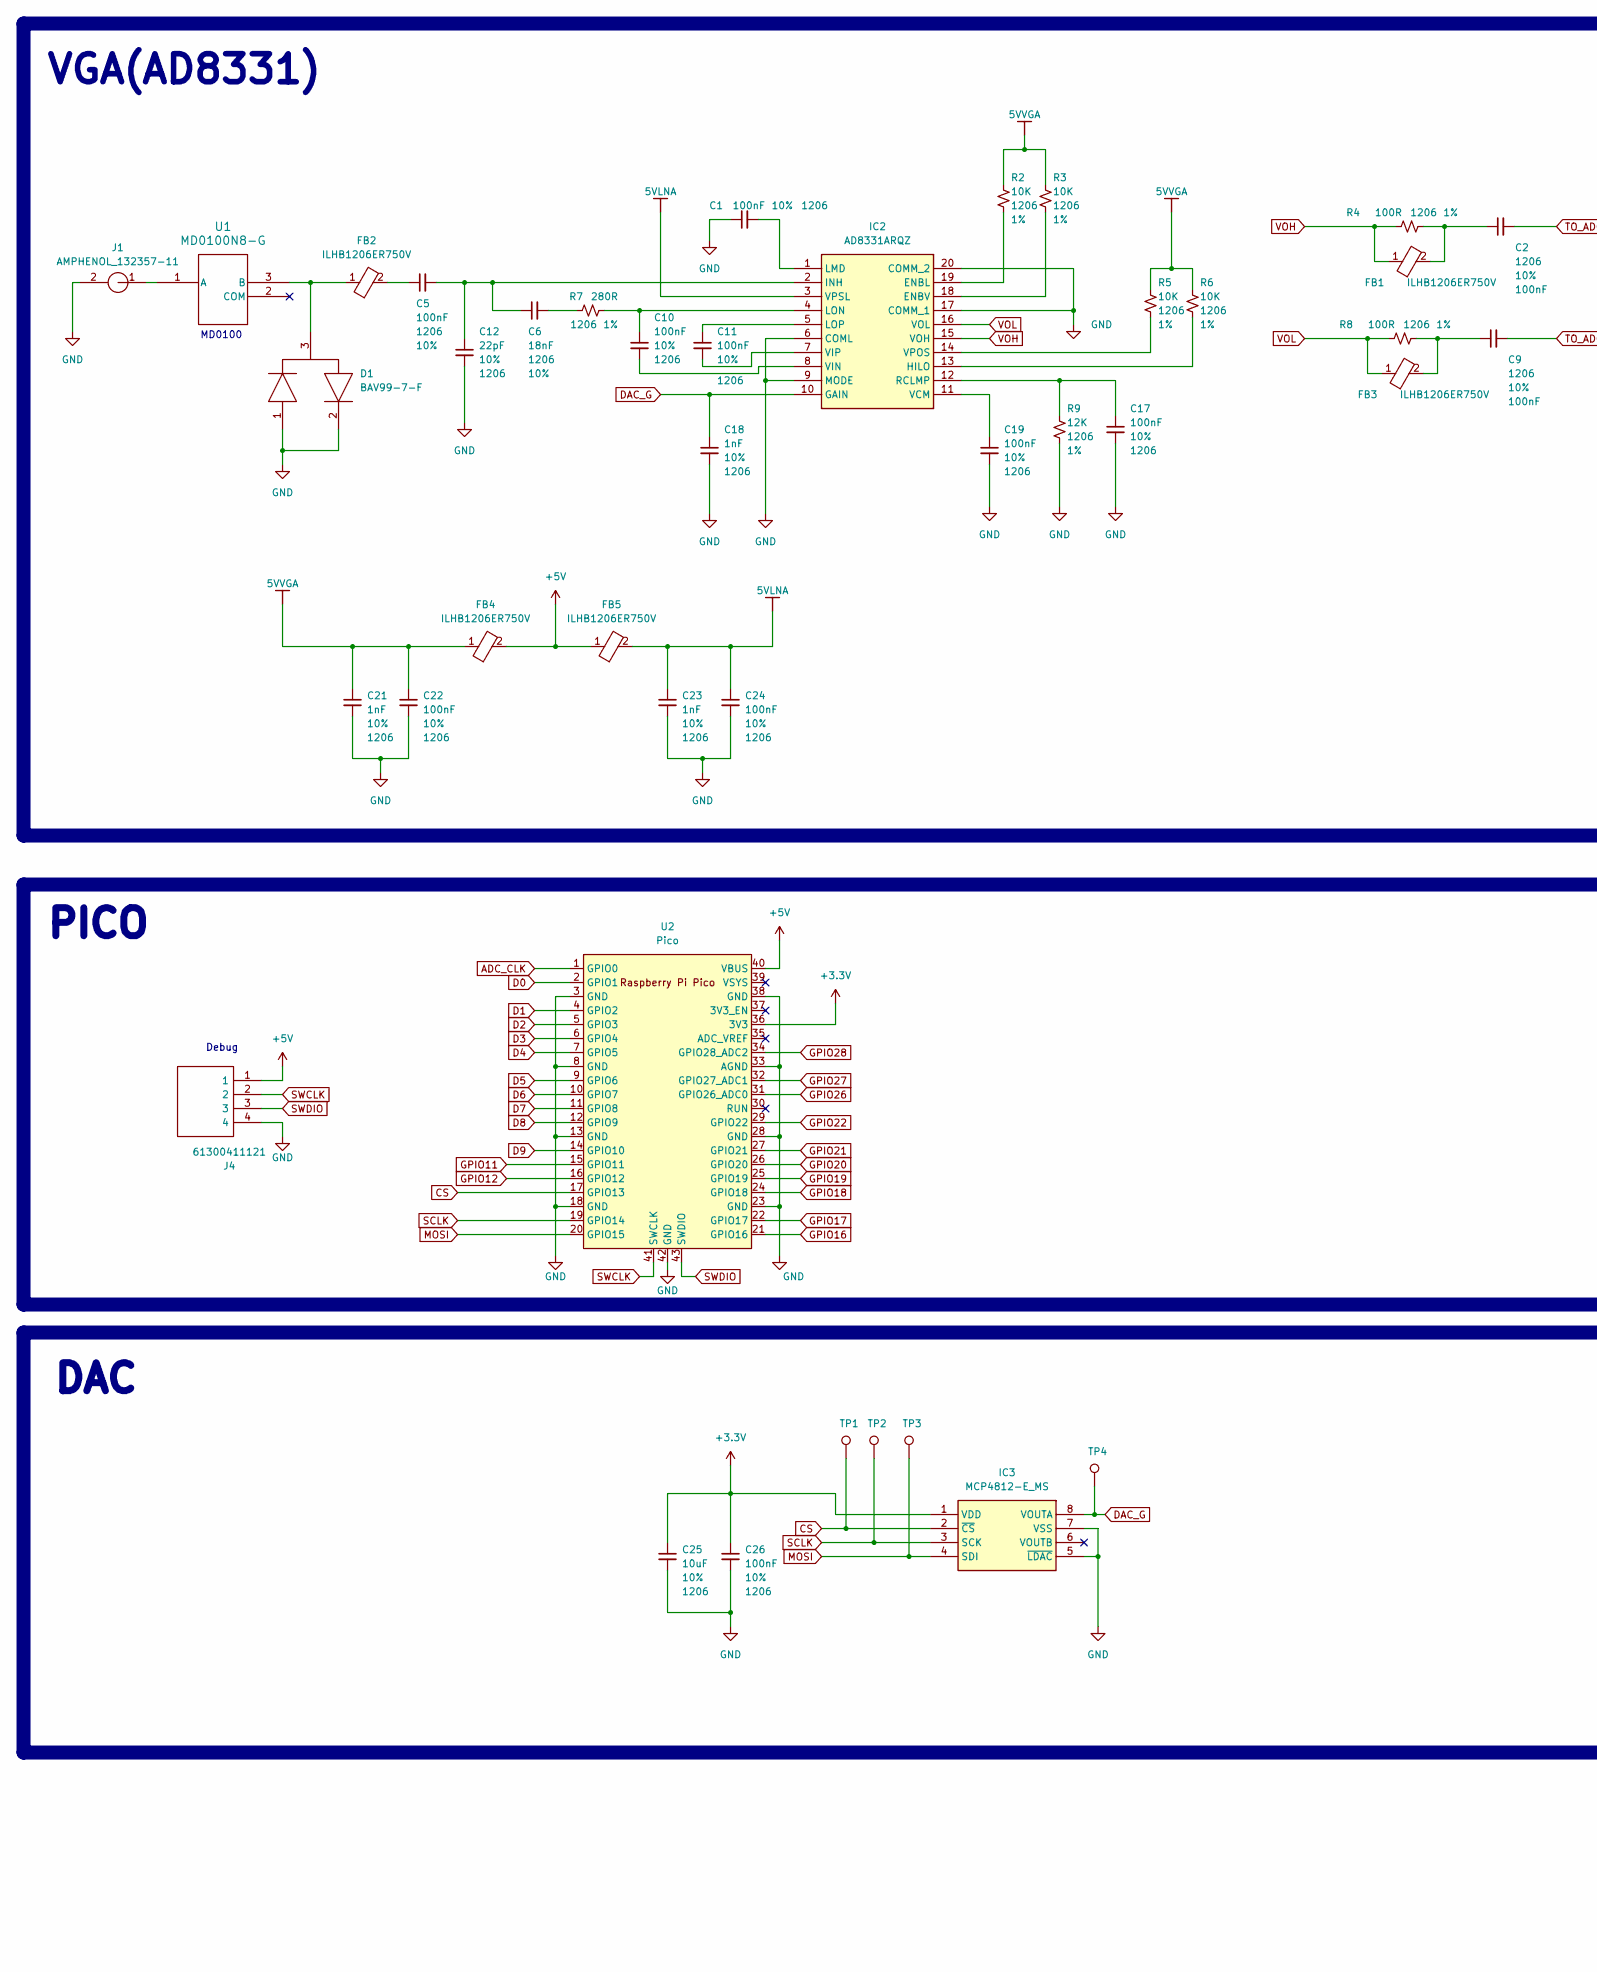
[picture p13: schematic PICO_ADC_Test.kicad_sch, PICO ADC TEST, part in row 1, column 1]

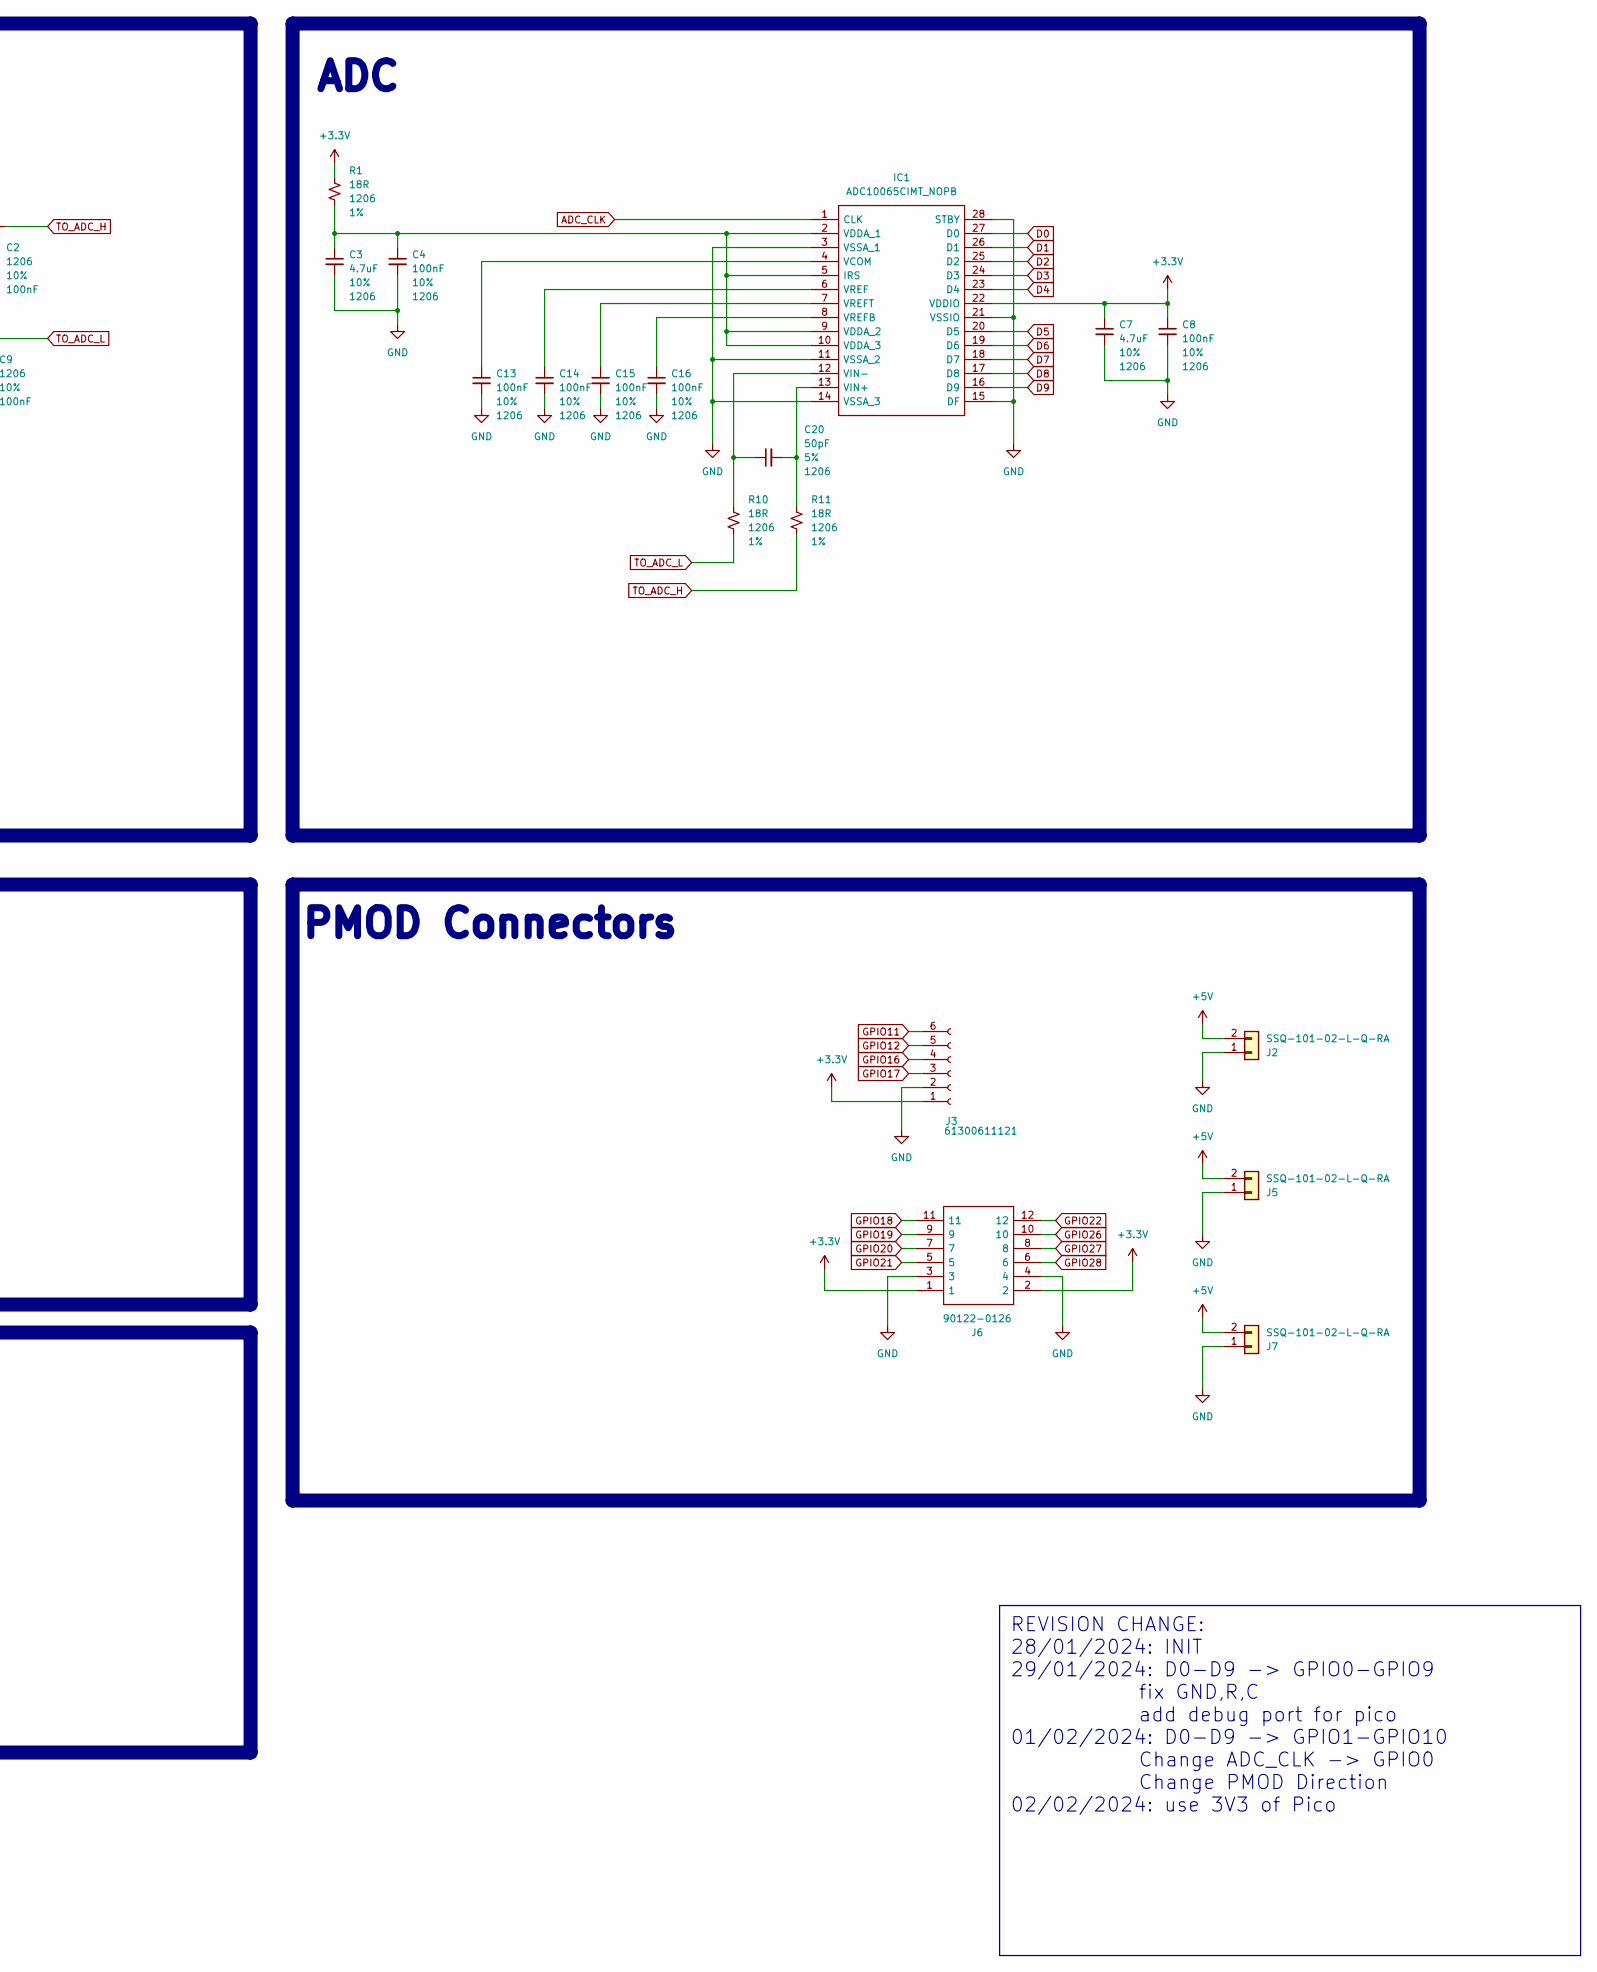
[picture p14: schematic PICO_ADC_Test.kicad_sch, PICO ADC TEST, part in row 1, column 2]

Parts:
C1, C2, C4, C5, C8, C9, C10, C11, C13, C14, C15, C16, C17, C19, C22, C24, C26: 100nF; C_1206_3216Metric; Tolerance 10%; MPN VJ1206Y104KXQCW1BC
C3, C7: 4.7uF; C_1206_3216Metric; Tolerance 10%; MPN 1206ZD475KAT4A
C6: 18nF; C_1206_3216Metric; Tolerance 10%; MPN VJ1206Y183KXAAC
C12: 22pF; C_1206_3216Metric; Tolerance 10%; MPN VJ1206A220JXQPW1BC
C18, C21, C23: 1nF; C_1206_3216Metric; Tolerance 10%; MPN GRM31C5C3A102JWA3L
C20: 50pF; C_1206_3216Metric; Tolerance 5%; MPN 12062A500KAT2A
C25: 10uF; C_1206_3216Metric; Tolerance 10%; MPN KAF31GR71C106KU
D1: BAV99-7-F; SOT95P240X120-3N; Mouser Part Number 621-BAV99-F
FB1, FB2, FB3, FB4, FB5: ILHB1206ER750V; L_1206_3216Metric; Tolerance 25%; Mouser Part Number 81-BLM21B750S
IC1: ADC10065CIMT_NOPB; SOP65P640X120-28N; Mouser Part Number 926-ADC10065CIMTNOPB
IC2: AD8331ARQZ; SOP64P600X175-20N; MANUFACTURER_PART_NUMBER AD8331ARQZ; MOUSER PART NUMBER 584-AD8331ARQZ
IC3: MCP4812-E_MS; MCP4812-EMS; MANUFACTURER_PART_NUMBER MCP4812-E/MS; MOUSER PART NUMBER 579-MCP4812-E/MS
J1: AMPHENOL_132357-11; Mouser Part Number 530-142-0701-801
J2, J5, J7: SSQ-101-02-L-Q-RA; PinHeader_1x02_P2.54mm_Vertical; MPN SSQ-101-02-L-Q-RA
J3: 61300611121; PinSocket_1x06_P2.54mm_Horizontal; Mouser Part Number 710-613006143121
J4: 61300411121; PinHeader_1x04_P2.54mm_Vertical; Mouser Part Number 710-61300411121
J6: 90122-0126; PinSocket_2x06_P2.54mm_Horizontal; MPN 613012243121; Mouser Part Number 710-613012243121
R1, R10, R11: 18R; R_1206_3216Metric; Tolerance 1%; MPN WSL1206R1800FEA
R2, R3, R5, R6: 10K; R_1206_3216Metric; Tolerance 1%; MPN 1206W4F1002T5E
R4, R8: 100R; R_1206_3216Metric; Tolerance 1%; MPN 560112132023
R7: 280R; R_1206_3216Metric; Tolerance 1%; MPN CR1206-FX-2800ELF
R9: 12K; R_1206_3216Metric; Tolerance 1%; MPN CR1206-FX-1202ELF
TP1, TP2, TP3, TP4: TestPoint; TestPoint_Pad_D1.0mm
U1: MD0100N8-G; SOT-89-3; MPN MD0100N8-G
U2: Pico; RPi_Pico_SMD; MPN Pico

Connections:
5VLNA: C23.1, C24.1, FB5.2, IC2.3 (VPSL)
5VVGA: C21.1, C22.1, FB4.1, R2.1, R3.1, R5.1, R6.1
+3.3V: C7.1, C8.1, C25.1, C26.1, IC1.22 (VDDIO), IC3.1 (VDD), J3.1, J6.1, J6.2, R1.1, U2.36 (3V3)
+5V: FB4.2, FB5.1, J2.2, J4.1, J5.2, J7.2, U2.40 (VBUS)
ADC_CLK: IC1.1 (CLK), U2.1 (GPIO0)
CS: IC3.2 (~CS), TP1.1, U2.17 (GPIO13)
D0: IC1.27 (D0), U2.2 (GPIO1)
D1: IC1.26 (D1), U2.4 (GPIO2)
D2: IC1.25 (D2), U2.5 (GPIO3)
D3: IC1.24 (D3), U2.6 (GPIO4)
D4: IC1.23 (D4), U2.7 (GPIO5)
D5: IC1.20 (D5), U2.9 (GPIO6)
D6: IC1.19 (D6), U2.10 (GPIO7)
D7: IC1.18 (D7), U2.11 (GPIO8)
D8: IC1.17 (D8), U2.12 (GPIO9)
D9: IC1.16 (D9), U2.14 (GPIO10)
DAC_G: C18.1, IC2.10 (GAIN), IC3.8 (VOUTA), TP4.1
GND: C1.1, C3.2, C4.2, C7.2, C8.2, C12.2, C13.2, C14.2, C15.2, C16.2, C17.2, C18.2, C19.2, C21.2, C22.2, C23.2, C24.2, C25.2, C26.2, D1.1, D1.2, IC1.3 (VSSA_1), IC1.11 (VSSA_2), IC1.14 (VSSA_3), IC1.15 (DF), IC1.21 (VSSIO), IC1.28 (STBY), IC2.6 (COML), IC2.9 (MODE), IC2.17 (COMM_1), IC2.20 (COMM_2), IC3.5 (~LDAC), IC3.7 (VSS), J1.2, J2.1, J3.2, J4.4, J5.1, J6.3, J6.4, J7.1, R9.2, U2.3 (GND), U2.8 (GND), U2.13 (GND), U2.18 (GND), U2.23 (GND), U2.28 (GND), U2.33 (AGND), U2.38 (GND), U2.42 (GND)
GPIO11: J3.6, U2.15 (GPIO11)
GPIO12: J3.5, U2.16 (GPIO12)
GPIO16: J3.4, U2.21 (GPIO16)
GPIO17: J3.3, U2.22 (GPIO17)
GPIO18: J6.11, U2.24 (GPIO18)
GPIO19: J6.9, U2.25 (GPIO19)
GPIO20: J6.7, U2.26 (GPIO20)
GPIO21: J6.5, U2.27 (GPIO21)
GPIO22: J6.12, U2.29 (GPIO22)
GPIO26: J6.10, U2.31 (GPIO26_ADC0)
GPIO27: J6.8, U2.32 (GPIO27_ADC1)
GPIO28: J6.6, U2.34 (GPIO28_ADC2)
MOSI: IC3.4 (SDI), TP3.1, U2.20 (GPIO15)
unnamed: C2.1, FB1.2, R4.2
unnamed: C5.1, FB2.2
unnamed: C6.2, R7.1
unnamed: C9.1, FB3.2, R8.2
unnamed: C3.1, C4.1, IC1.2 (VDDA_1), IC1.5 (IRS), IC1.9 (VDDA_2), IC1.10 (VDDA_3), R1.2
unnamed: C13.1, IC1.4 (VCOM)
unnamed: C20.2, IC1.13 (VIN+), R11.1
unnamed: C20.1, IC1.12 (VIN-), R10.1
unnamed: C14.1, IC1.6 (VREF)
unnamed: C16.1, IC1.8 (VREFB)
unnamed: C15.1, IC1.7 (VREFT)
unnamed: IC2.19 (ENBL), R2.2
unnamed: IC2.18 (ENBV), R3.2
unnamed: IC2.13 (HILO), R6.2
unnamed: C5.2, C6.1, C12.1, IC2.2 (INH)
unnamed: C1.2, IC2.1 (LMD)
unnamed: C10.1, IC2.4 (LON), R7.2
unnamed: C11.1, IC2.5 (LOP)
unnamed: C17.1, IC2.12 (RCLMP), R9.1
unnamed: C19.1, IC2.11 (VCM)
unnamed: C10.2, IC2.8 (VIN)
unnamed: C11.2, IC2.7 (VIP)
unnamed: IC2.14 (VPOS), R5.2
unnamed: J1.1, U1.1 (A)
unnamed: D1.3, FB2.1, U1.3 (B)
SCLK: IC3.3 (SCK), TP2.1, U2.19 (GPIO14)
SWCLK: J4.2, U2.41 (SWCLK)
SWDIO: J4.3, U2.43 (SWDIO)
TO_ADC_H: C2.2, R11.2
TO_ADC_L: C9.2, R10.2
VOH: FB1.1, IC2.15 (VOH), R4.1
VOL: FB3.1, IC2.16 (VOL), R8.1

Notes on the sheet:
PMOD Connectors
DAC
PICO
VGA(AD8331)
Debug
MD0100
ADC
REVISION CHANGE: 28/01/2024: INIT 29/01/2024: D0-D9 -> GPIO0-GPIO9 fix GND,R,C add debug port for pico 01/02/2024: D0-D9 -> GPIO1-GPIO10 Change ADC_CLK -> GPIO0 Change PMOD Direction 02/02/2024: use 3V3 of Pico

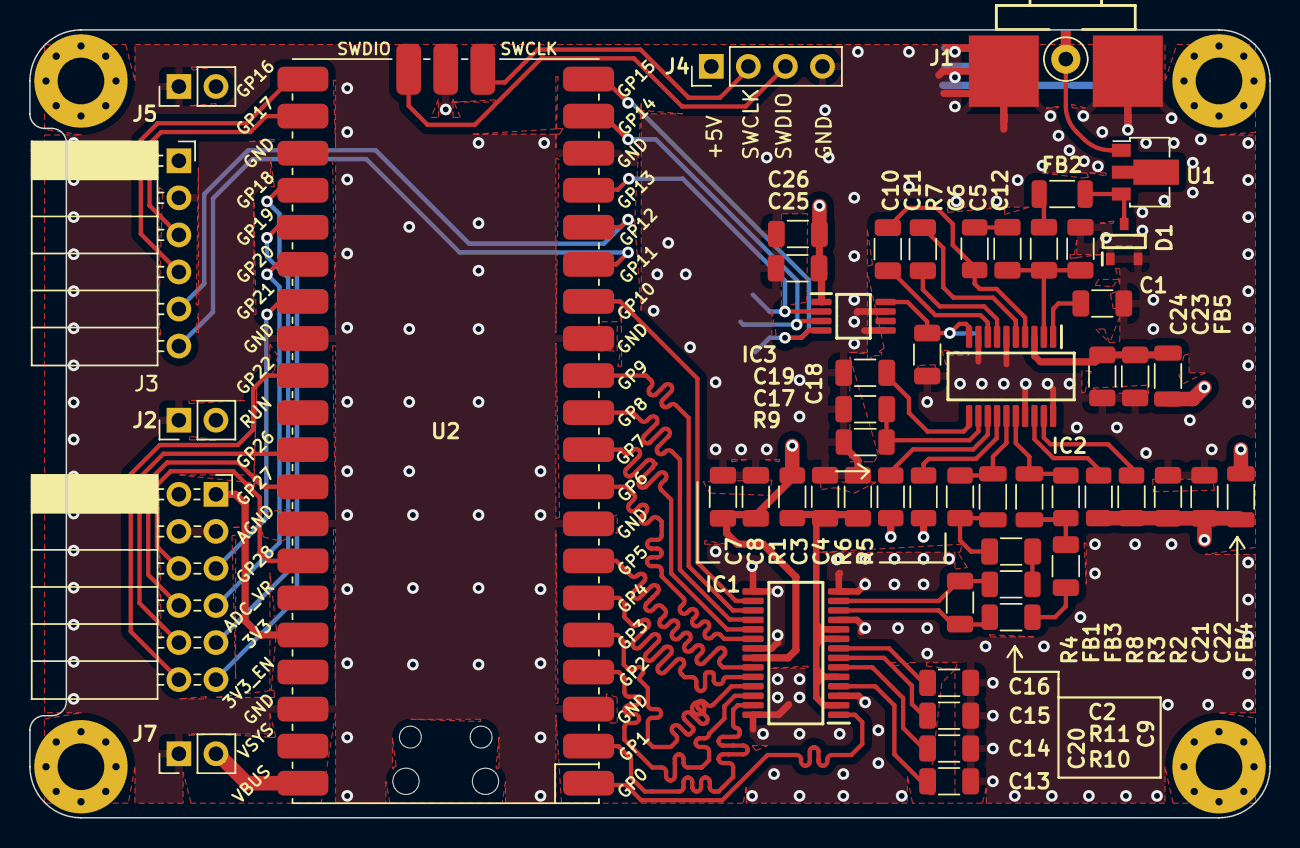
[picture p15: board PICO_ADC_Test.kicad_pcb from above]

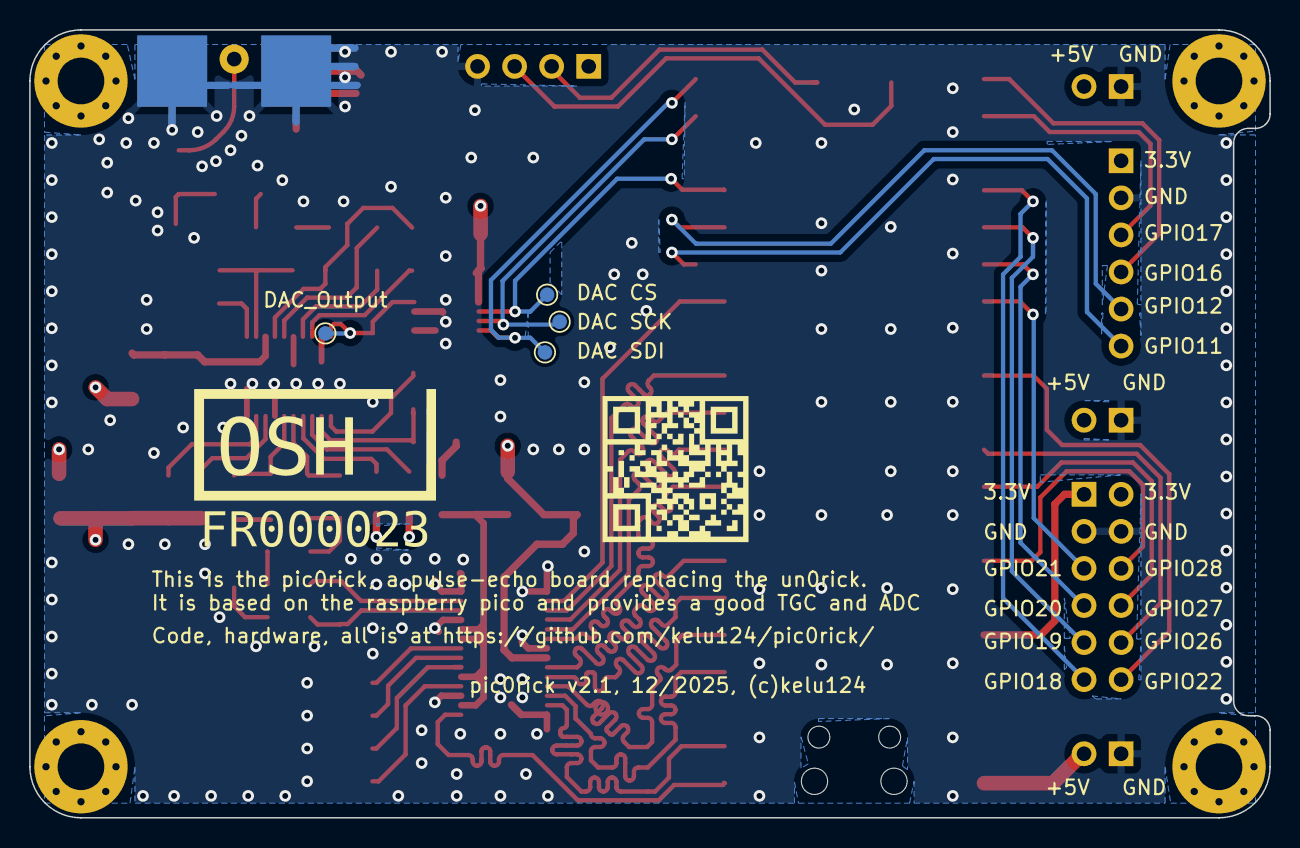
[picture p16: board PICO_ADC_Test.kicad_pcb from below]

Board: 4 copper layers, 85.0 x 54.0 mm, 59 parts (4 on the bottom side), 63 nets.

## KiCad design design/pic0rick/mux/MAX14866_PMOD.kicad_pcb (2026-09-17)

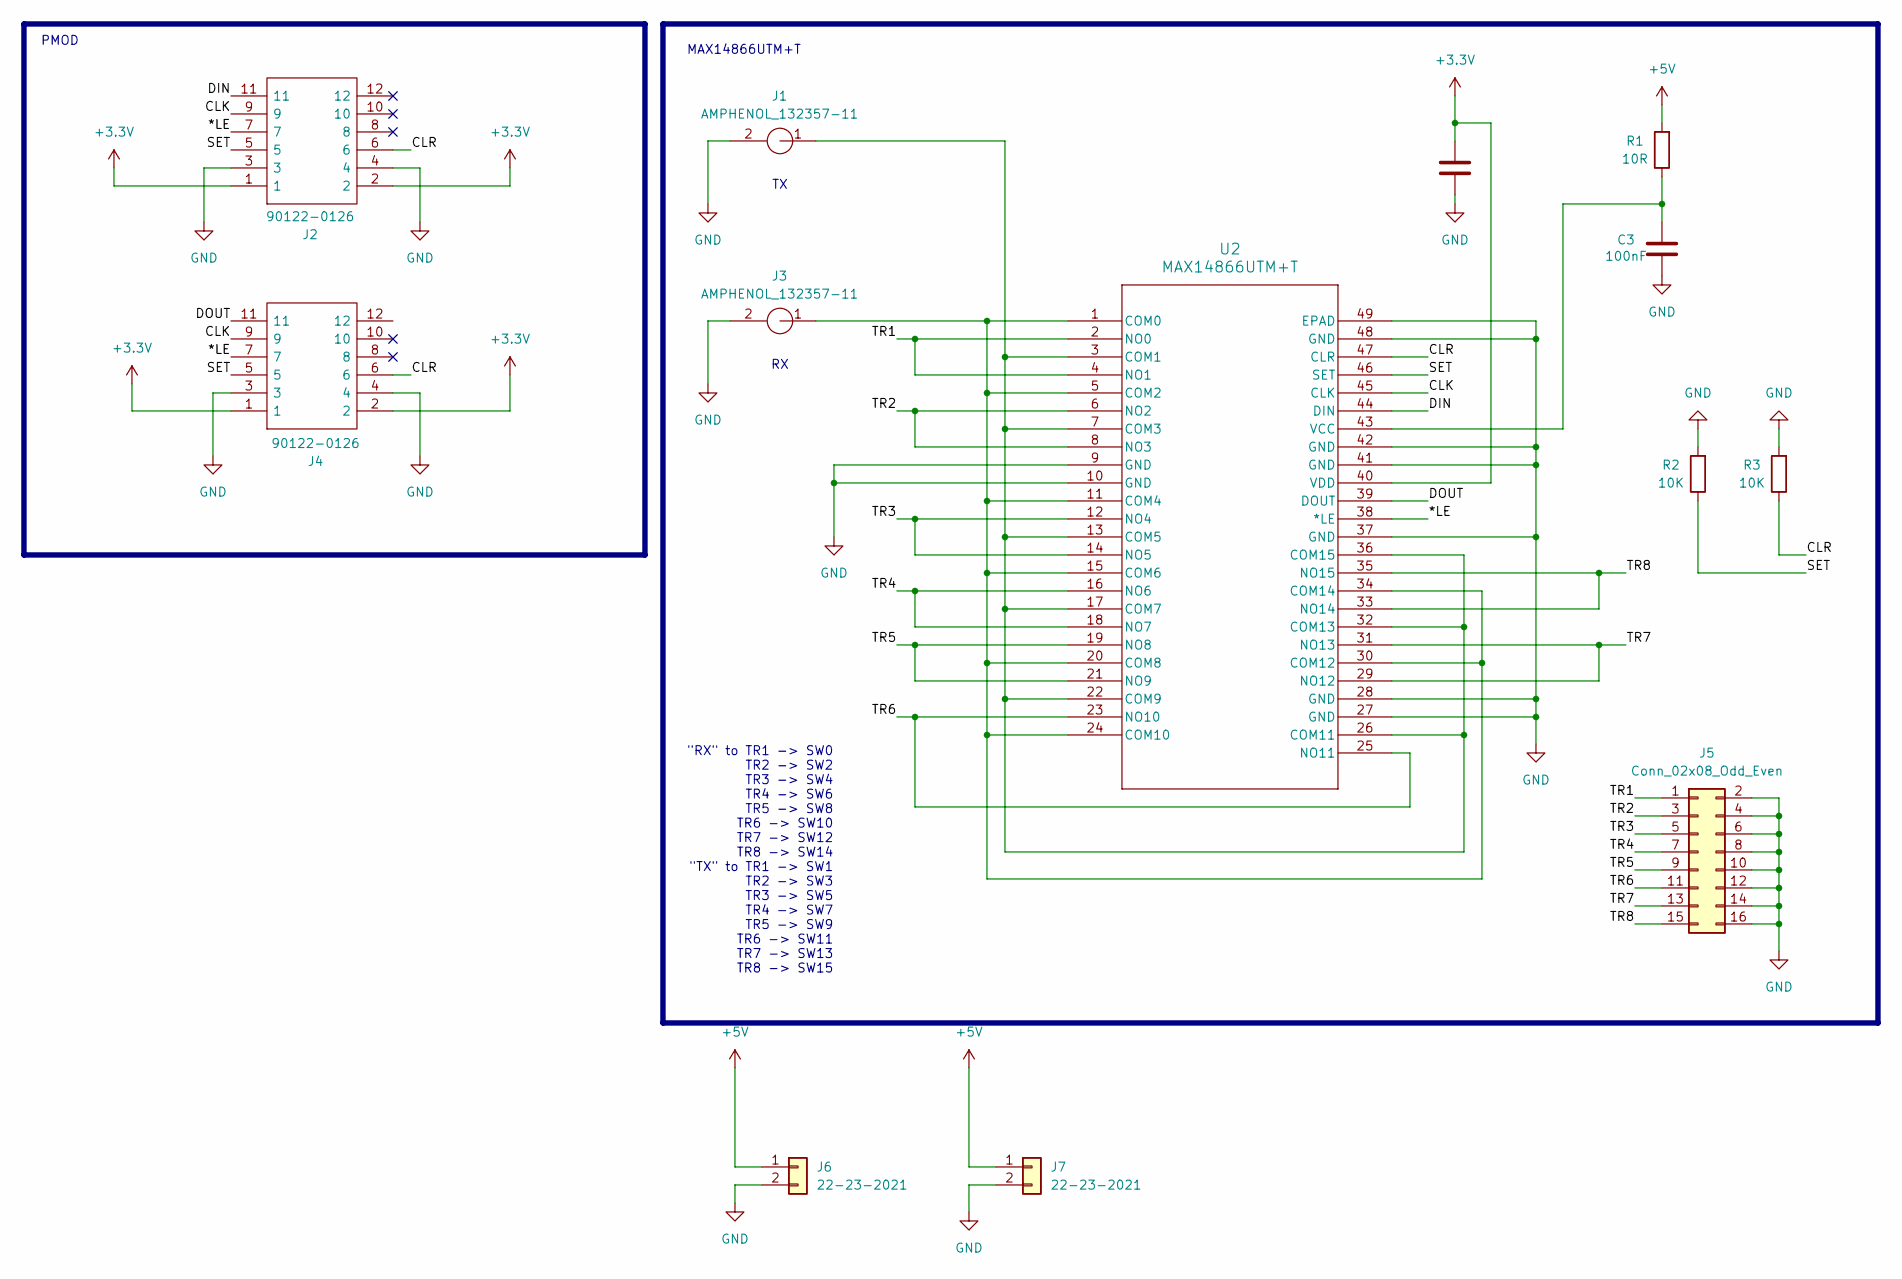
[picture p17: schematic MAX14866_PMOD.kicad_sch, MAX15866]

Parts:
C2: 1uF; C_1206_3216Metric
C3: 100nF; C_1206_3216Metric
J1, J3: AMPHENOL_132357-11; AMPHENOL_132357-11-MOD; Mouser Part Number 530-142-0701-801
J2: 90122-0126; PinHeader_2x06_P2.54mm_Horizontal; Mouser Part Number 710-613012243121
J4: 90122-0126; PinSocket_2x06_P2.54mm_Horizontal; Mouser Part Number 710-613012243121
J5: Conn_02x08_Odd_Even; PinHeader_2x08_P2.54mm_Vertical
J6: 22-23-2021; PinSocket_2x01_P2.54mm_Horizontal; MPN 22-23-2021
J7: 22-23-2021; PinHeader_2x01_P2.54mm_Horizontal; MPN 22-23-2021
R1: 10R; R_1206_3216Metric
R2, R3: 10K; R_1206_3216Metric
U2: MAX14866UTM+T; 21-0144H_T4877-6_MXM

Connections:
+3.3V: C2.2, J2.1, J2.2, J4.1, J4.2, U2.40 (VDD)
+5V: J6.1, J7.1, R1.2
/*LE: J2.7, J4.7, U2.38 (*LE)
/CLK: J2.9, J4.9, U2.45 (CLK)
/CLR: J2.6, J4.6, R3.1, U2.47 (CLR)
/DIN: J2.11, U2.44 (DIN)
/DOUT: J4.11, U2.39 (DOUT)
/SET: J2.5, J4.5, R2.1, U2.46 (SET)
/TR1: J5.1, U2.2 (NO0), U2.4 (NO1)
/TR2: J5.3, U2.6 (NO2), U2.8 (NO3)
/TR3: J5.5, U2.12 (NO4), U2.14 (NO5)
/TR4: J5.7, U2.16 (NO6), U2.18 (NO7)
/TR5: J5.9, U2.19 (NO8), U2.21 (NO9)
/TR6: J5.11, U2.23 (NO10), U2.25 (NO11)
/TR7: J5.13, U2.29 (NO12), U2.31 (NO13)
/TR8: J5.15, U2.33 (NO14), U2.35 (NO15)
GND: C2.1, C3.1, J1.2, J2.3, J2.4, J3.2, J4.3, J4.4, J5.2, J5.4, J5.6, J5.8, J5.10, J5.12, J5.14, J5.16, J6.2, J7.2, R2.2, R3.2, U2.9 (GND), U2.10 (GND), U2.27 (GND), U2.28 (GND), U2.37 (GND), U2.41 (GND), U2.42 (GND), U2.48 (GND), U2.49 (EPAD)
unnamed: J3.1, U2.1 (COM0), U2.5 (COM2), U2.11 (COM4), U2.15 (COM6), U2.20 (COM8), U2.24 (COM10), U2.30 (COM12), U2.34 (COM14)
unnamed: J1.1, U2.3 (COM1), U2.7 (COM3), U2.13 (COM5), U2.17 (COM7), U2.22 (COM9), U2.26 (COM11), U2.32 (COM13), U2.36 (COM15)
unnamed: C3.2, R1.1, U2.43 (VCC)

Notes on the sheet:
PMOD
MAX14866UTM+T
"RX" to TR1 -> SW0 TR2 -> SW2 TR3 -> SW4 TR4 -> SW6 TR5 -> SW8 TR6 -> SW10 TR7 -> SW12 TR8 -> SW14 "TX" to TR1 -> SW1 TR2 -> SW3 TR3 -> SW5 TR4 -> SW7 TR5 -> SW9 TR6 -> SW11 TR7 -> SW13 TR8 -> SW15

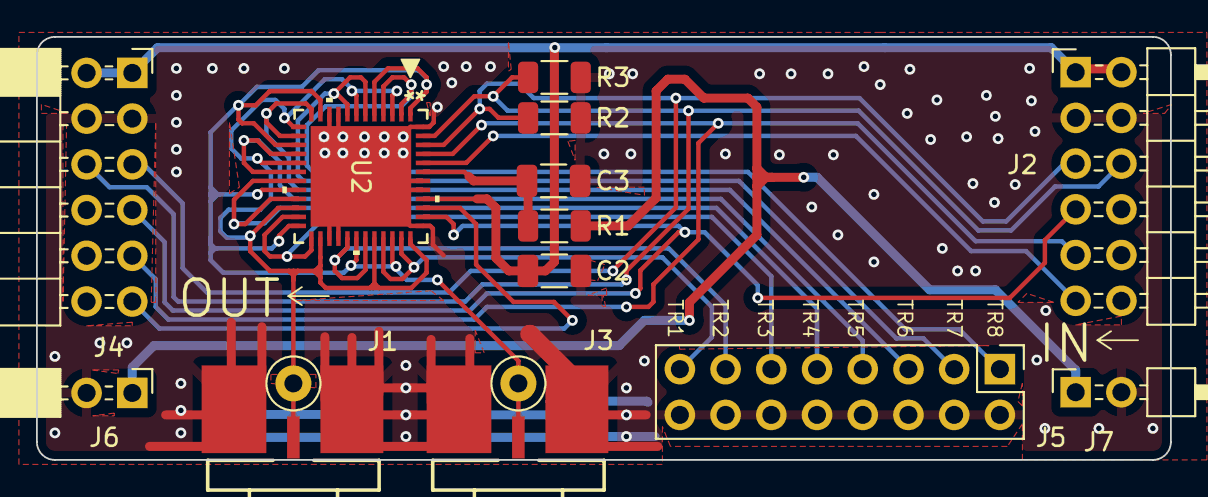
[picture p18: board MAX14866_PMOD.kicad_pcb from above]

Board: 2 copper layers, 63.0 x 23.5 mm, 13 parts (0 on the bottom side), 20 nets.

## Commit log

2026-09-17 docs: set up Claude documentation & memory system
    Establish the working conventions for the minus project:
    - docs/claude/ with session logs, memory store (+ INDEX), TODO/DONE, changelog
    - CLAUDE.md session rules: come-up-to-speed on start, log discussions,
    persist decisions, track work, summarize every commit in the changelog
    - repo-scoped skill .claude/skills/minus-docs packaging these rules (repo only)
2026-09-17 survey: add lightweight ultrasound systems datasheets
    Add systems/ background survey used to inform minus:
    - systems/TEMPLATE.md: 10-section device datasheet (MCU/FPGA, pulser
    polarity+voltage, acquisition route, ADC, gain/TGC, connectivity, wireless,
    channels, performance, power)
    - systems/README.md: index + at-a-glance comparison table
    - one populated sheet per system: EchoLite, PuLsE, USoP, WULPUS, WULPUS PRO,
    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
2026-09-17 survey: add IUP + MEMS-US, literature review, pdfs/ & design/
    Process user-provided PDFs and set up artifact storage:
    - systems/iup: HZDR DRESDYN UDV single-channel node (STM32H7+iCE40, MD1213/
    TC6320, AD8331, MD0100, LTC2203 16-bit@16MHz, SD/SDRAM, ESP32 Wi-Fi, 2.96 W)
    - systems/mems-us: POSTECH single-element real-time B-mode via MEMS mirror scanner
    - systems/literature.md: distilled from Jonveaux et al. 2022 open-hardware review
    (Table 2 filtered to <=32 elements + pulser/HV/TGC/ADC/AFE component menus +
    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
2026-09-17 survey: design files + Weik 2026 review + SIG-WUS, 4 new sheets
    Design files (from upstream repos, with SOURCE.md + commit SHAs):
    - design/un0rick, design/lit3rick: schematic PDFs, BOMs, gerbers, drills
    - design/pic0rick: KiCad + schematic PDFs + gerbers for adc, mux, and the
    3-in-1 adc+pulser+hv panel; article -> pdfs/pic0rick_full.pdf
    - cross-linked from the matching systems/ datasheets
    Literature + new systems (Weik et al. 2026, IEEE RBME; SIG-WUS OXP basis):
    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
    [3_in_1_Panel-BOM.csv, 3_in_1_Panel.kicad_pcb, 3_in_1_Panel.kicad_sch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]
2026-09-17 survey: SIG-WUS OXP catalog data, FloPatch detail, BioGAP shield
    - systems/_sig-wus-oxp/: snapshot of the SIG-WUS OXP catalog pulled from its repo
    JSON (live site failed to load) — 14 platforms + reconciliation table
    - FloPatch: enrich to FP120, continuous-wave 4 MHz, FDA-cleared (K200337, 2020) +
    CE, Flosonics Medical (Toronto), iOS app (velocity/VTI/ccFT), Kenny et al. 2021
    - correct SENS-U -> TENA SmartCare (Essity), 2021, pediatric
    - add systems/biogap-wulpus-pro (ETH open shield pulp-bio/sensei-us-shield);
    cross-ref from wulpus-pro (systems/ = 18 sheets)
    - conventions: add 45 MB per-file cap (CLAUDE.md, minus-docs skill, memory 0002)
    - update README/literature/memory/TODO/DONE/l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
2026-09-17 survey: by-IC cross-ref (MSP430FR5043, TUSS4470) + Open Echo + design files
    - systems/by-ic.md: designs grouped by key IC, per request
    - MSP430FR5043: WULPUS, WULPUS PRO, BioGAP WULPUS-pro, EMG+A-mode fusion, TI EVM
    - TUSS4470: Open Echo (Neumi/open_echo) + TI BOOSTXL EVM; +recurring-parts index
    - systems/open-echo: datasheet for the open TUSS4470 Arduino-shield sonar
    - design/biogap-wulpus-pro: schematics/assembly PDF + BOM (pulp-bio/sensei-us-shield)
    - design/open-echo: KiCad + gerbers + BOM (Neumi/open_echo, current _002 board)
    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
    [BOM_WULPUS_pro_BioGAP_shield.xlsx, TUSS4470_shield-bom.csv, TUSS4470_shield.kicad_pcb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]
2026-09-17 analysis: routes + light-BOM pulsers; per-system 1-5 MHz + sampling attrs
    - add two attributes to all 19 system sheets (callout under Classification):
    "Piezo 1-5 MHz" compatibility and "ADC sampling speed"; add to TEMPLATE.md;
    consolidated quick-reference table in systems/README.md
    - analysis.md (root, first pass): integrated routes (MSP430 <=3 MHz / TUSS4470
    <=1 MHz) vs external-ADC route (1-5 MHz); recommends external-ADC for a 1-5 MHz
    minus; light-BOM pulser options table (TUSS4470 / STHV748 / MD1213+TC6320 /
    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
2026-09-17 docs: draft requirements.md (v0.1)
    First requirements document for minus: MoSCoW-prioritised requirements across
    functional, performance, analog front-end, transmit/pulser, digitization, control/
    connectivity, power, mechanical, cost/BOM, software, openness, and safety, plus a
    verification/acceptance table and traceability to systems/ + analysis.md. Section 4
    captures the open decisions (TBD-1..7) to resolve for v1.0. Cross-linked from
    analysis.md; memory 0005 + docs updated.
    Claude-Session: https://claude.ai/code/session_01BmEqK4CNMtQ9Fs5o9KMo7D
2026-09-17 docs: requirements v0.2 — RP2350 MCU, on-board USB-C, small/cheap/simple
    Lock owner decisions:
    - design principles DP1-DP4: smallest board, cheapest BOM, simplest design,
    RP2350 MCU
    - resolve TBD-4 (host link = USB via on-board USB-C connector, bus-powered) and
    TBD-7 (controller = RP2350; RP2350B preferred)
    - architecture note: RP2350 on-chip ADC = 500 kSps (too slow for 1-5 MHz raw RF)
    => external high-speed ADC clocked into PIO (trimmed pic0rick on RP2350); new
    open item ADEC for the ADC choice
    - update controller/power/mechanical/data reqs + memory 0005 + docs
    Claude-Session: https://claude.ai/code/session_01BmEqK4CNMtQ9Fs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
2026-09-17 docs: requirements v0.3 — NDT workshop badge, 3-4 MHz unipolar, coded excitation
    Fold in a batch of owner decisions:
    - use: non-clinical NDT/education; conference WORKSHOP BADGE (limited budget, many
    units); example topic muscle-contraction monitoring (A-/M-mode); piezo PROVIDED
    with the kit (not in board BOM)
    - signal: target 3-4 MHz; unipolar pulser (simplest); A-mode + M-mode; B-mode deferred
    - excitation: programmable/coded excitation via RP2350 PIO (chirp/pulse-train/OOK);
    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
2026-09-17 docs: requirements — friendly-layout, test points, extension + external-HV headers
    - M5 [S]: user-friendly silkscreen (label blocks/connectors/pins, function hints)
    - M6 [S]: test points on key logic/analog nodes for probing/learning
    - C5 [S]: extension headers exposing spare RP2350 PIO/GPIO + power for add-on boards
    - T7 [S]: HV rail(s) on a header w/ jumper to isolate on-board HV and feed/replace
    with external HV
    - memory 0005 updated (changelog line rides to next commit)
    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
2026-09-17 docs: options.md trade study + priced CSV; gain alternatives; 5V/±5V HV
    - options.md (root): filtered shortlist of pulser / gain / ADC options vs minus
    criteria (subset of analysis.md), with per-option pricing and candidate builds
    (~$16 cheapest active-IC BOM -> ~$44 derisked)
    - options_prices.csv: per-part prices (LCSC qty 20-50, active parts only)
    - analysis.md 3b: gain (VGA/TGC) alternatives to AD8331 (AD8338/AD8330/AD603/
    integrated AFEs/log-amp)
    - HV options: U0 5V-rail-only (no boost); B0 cheap +/-5V via +5->-5V charge pump
    (TPS60403/ICL7660/LM2776) -> true low-amplitude phase codes
    - requirements: open question RF-ACCESS (raw RF vs envelope); T3/T6 updated
    - memory 0006 (pric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
    [options_prices.csv]
2026-09-17 docs: real LCSC prices+URLs+stock in options; ADC bottleneck; TXRX-LINK question
    - options_prices.csv: add source_url + stock columns, real LCSC figures
    (RP2350B ~1.06, AD8331 ~10 in-stock, AD9235-20 ~17.9 in-stock, TC6320 ~2.03,
    LM2776 ~0.48); flag AD8338/AD9200 OUT OF STOCK and MD1213 not on LCSC
    - options.md: availability reality-check; in-stock realistic build ~$33 (ADC is the
    cost+availability bottleneck) vs theoretical floor ~$14 (needs restock); gain/ADC
    picks re-ranked by stock (AD8331 now pragmatic)
    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
    [options_prices.csv]
2026-09-17 docs: record cheaper 8-bit ADC candidates to verify on LCSC (ADEC)
    - options_prices.csv + options.md: add TLC5540 / ADS830 (and AD9280) as cheaper
    ~$3-5 8-bit high-speed ADC candidates to verify directly on LCSC (web search
    inconclusive); note 8-bit ~48 dB is marginal vs P5 (>=50 dB SNR)
    - ADEC (external ADC choice) remains the open cost/availability driver
    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
    [options_prices.csv]
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2026-09-17 docs: rewrite root README as a project overview for visitors
    Replace the placeholder README with an overview: what minus is (open single-channel
    ultrasound workshop badge on RP2350), status (early design), a features-at-a-glance
    list, a repository map, lineage/credits (kelu124 boards), and license intent.
    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
2026-09-18 design(A): Ubuntu CLI toolchain + reuse of kelu124/pic32arick blocks
    - Add design/designA/toolchain_designA.md: Linux CLI + Makefile flow —
    RP2354 pico-sdk/CMake -> uf2 (+ picotool); PIC32A XC-DSC -> hex via
    ipecmd/PICkit (or mdb); top-level Makefile. XC-DSC confirmed Linux + PIC32A.
    - Fold pic32arick (owner's PIC32AK board) into DesignA + pic32.md:
    push-pull pulser IRLML6244/2244 + TC4427A gate driver + MD0100 T/R;
    3-op-amp gain chain (fixed OA1 + MCP4531 I2C digipot OA2 + bias OA3);
    6-pin ICSP with 47ohm series R, Tag-Connect, and off-center friction-fit
    holes (Microchip gpdim demo) for solderless programming.
    - BOM now ~$4.7 active / ~$6.3 board (single-N-FET min variant ~$5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
2026-09-21 design: add DesignA-DK devkit (derisking board) spec
    New design/devkit/README.md — a large, fully broken-out RP2354A + PIC32AK
    development kit to derisk front-end/gain/pulser decisions before freezing the
    cheap DesignA badge:
    - Core: RP2354A + PIC32AK6416GC41064 (64-pin/16KB), split AVDD/DVDD rails with
    current sense, both programming paths, all pins broken out.
    - Swappable RX front-ends on a standard mezzanine (FE-0 straight, FE-A PIC-opamp,
    FE-B LNA+opamp, FE-C AD8331, FE-D AD8338) + ADC-source jumper.
    - Gain-control options (MCP4531 I2C / MCP4131 SPI / resistor-mux / VGA Vgain).
    - Pulser bench (push-pull or single-FET, HV-rail select, damping, JP1, MD0100/BAV99).
    - SMA taps + loopba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
2026-09-21 docs: ADC input conditioning + TX-coupled acquisition + PIC32AK datasheet
    - Mirror full PIC32AK datasheet DS70005592 (36 MB) + Flash Programming Spec
    DS70005583 into pdfs/datasheets/, each with a markitdown .md sibling; indexed.
    - DesignA §5a: single-supply ADC input conditioning (0->VREF single-ended,
    mid-rail 1.65V bias via OA3, AC-couple, ~2.6-2.8 Vpp fit, overrange clamp,
    per-line-gain auto-range). §5b: TX<->ADC hardware trigger (HS-PWM same counter,
    PTG, window mode; PIC-owns-TX for tightest). Tidy duplicate digipot bullet.
    - pic32 README §4: ADC input-range + ADC<->TX trigger facts; cite DS70005592.
    - requirements: A5 (single-supply mid-rail bias/clamp/~2.8 Vpp) + C1c
    (har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
2026-09-21 docs(devkit): add shareable PCB designer brief (B1–B11)
    Self-contained handoff section in design/devkit/README.md: board scope +
    4-layer/broken-out/jumper philosophy; RP2354A + PIC32AK6416GC41064; power &
    clocks (split AVDD/DVDD + current sense, ferrite-isolated pulser rail,
    QSPI_IOVDD 3.3V, VCAP, 12 MHz xtal); dual programming (UF2 + PIC ICSP header /
    Tag-Connect / friction-fit, 47R, shared net); inter-MCU bus; pulser bench
    (push-pull + TC4427A, JP1 drive-select, HV-rail select, MD1213 pads, MD0100/
    BAV99, TX<->ADC trigger); jumper-selected RX front-ends FE-0..FE-D + gain-control
    options + ADC input conditioning; connectors/SMA taps/loopback; layout guidance;
    KiCad deliverables; reference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
2026-09-21 docs: save design review findings + apply datasheet corrections across devkit
    - Add design/devkit/review-findings.md — consolidated 4-agent flaw review
    (severity-ranked A/B/C/D + open items + fix tracker).
    - Apply confirmed datasheet corrections in pic32/README, designA, devkit README
    and pcb-brief: reference = AVDD (no external VREF pin); op-amp 100MHz/100V/us is
    High-Power only (LP 50MHz/10V/us), offset +/-3mV max; ADC ENOB ~10.5-bit; op-amp
    input noise unspecified (LNA = bench call); TC4427A has no internal dead-time and
    is 8-pin (removed false dead-band/SOT-23-5 claims); pulser edges ~20-30ns.
    - pcb-brief.md: new "§0 must-fix before layout" (USB-C Rd, MCLR LVP-only/isolation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
2026-10-26 feat: devkit KiCad project (minUS_10102026) + first inter-MCU link firmware
    - Add hardware/minUS_10102026 (current DesignA-DK devkit, KiCad 10, JLCPCB production
    files) and the previous iteration minUS_08102026.
    - firmware/rp2354: pico-sdk project (board header minus_devkit.h, 2 MB flash), USB CDC
    CLI, UART0 PING/PONG link to the PIC32, TRIG/RDY, MCLR reset tap, PGC/PGD kept Hi-Z,
    WS2812 status LED. Builds with pico-sdk 2.1.0 -> minus_rp.uf2.
    - firmware/pic32: XC-DSC source for the PIC32AK1216GC41048 (FRC 8 MHz, PPS UART1 on
    RP39/RP40, PONG reply, RDY toggle, TRIG counter, LED2 heartbeat) + Makefile. Not yet
    compiled: XC-DSC / MPLAB X not installed.
    - firmware/README.md: netlist-ve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
2026-10-26 feat(firmware): STEP1.md, RP CLI (version/rgb/reboot dfu), semver rule, Makefiles, repo skills
    - STEP1.md: board fixes (R53 0R, cut JP1, R68/R69 -> one 1-4.7k), Ubuntu install steps for
    MPLAB X 6.35 / XC-DSC 4.00 / PIC32AK-GC_DFP 1.1.53, link test procedure.
    - rp2354: CLI gains version (fw+sdk version, chip id/package/revision, unique id), rgb R G B,
    reboot [dfu] (rom_reset_usb_boot); version.h 0.1.1; Makefile wrapper (build/flash/monitor).
    - pic32: config pragmas fixed against the DFP (JTAGEN=OFF, WDTEN=SW, WINDIS=ON, no ICS);
    register bitfield names verified against p32AK1216GC41048.h; version.h 0.1.0; Makefile
    resolves XC-DSC/MPLAB X/DFP paths (DFP unpacked in ~/microchip/packs),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
2026-10-26 chore(skills): fix kicad-netlist-reading after retrieval test; add minus-commit-log skill
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2026-10-27 feat(pic32): PLL 160/320 MHz clocks, UART baud clock fix (fw 0.1.1 wip)
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2026-10-27 fix(acq): review pass — SCCP1 32-bit timer trigger (T32), DMA status clear + overrun/bus-error reporting, bounded ADRDY wait, Makefile acq.h dep, capped link drain, parser bounds n
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2026-10-27 docs: bench debug log — pic id still silent with R53 shorted; SWD pad pull-up finding; next measurements
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2026-10-27 docs: bench conclusion — U2 silent with power/reset/sequence verified at its pins; replace the PIC
2026-10-27 docs: changelog/commit log — record the 2026-10-27 bench-debug commits; TODO RESUME HERE = replace U2
2026-10-27 docs: TODO_HARDWARE.md — corrections for the next devkit revision (ICSP reset path, JP1 default, SWD/J1, bus, LEDs, batch notes)
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2026-10-27 feat: first working RP<->PIC link and acq on board 2 — PIC UART pins fixed (pic 0.1.2), ACQ [div] with period-matched SAMC (pic 0.1.3 / rp 0.1.14, proto 3), DEVID = 0x9DA2 register value, lb loopback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
    Board 2: pic id ok, pic flash ok (verify 0 bad words), ping 1.2 ms, acq returns 4095
    samples. Fill time floor 153.8 us (26.6 Msps) for div 4..8 = DMA limit.
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2026-10-28 feat(firmware): acq input select (node/OA1OUT/OA1IN+) + op amp 1, bus-quiet DMA wait (20 Msps ceiling), acqcpu 40 Msps experiment, ADC throughput tests
    PIC 0.1.8-0.1.18 / RP 0.1.19-0.1.26, proto 4:
    - ACQ [div [samc [in [navg]]]]: ADC1 input select (9 node, 0 OA1OUT, 1 OA1IN+), integration-mode navg;
    AMP1 on at boot (AMPEN+HPEN), AMP1 0|1 on the link
    - DMA wait loop no longer polls DMA0STAT/TMR1 back-to-back: the CPU wins the SFR bus and the DMA then
    duplicated ~30% of the samples (session-05 "26.6 Msps" was that artefact). Real ceiling: 50 ns per
    transfer = 20 Msps; ACQ_TRIG_DIV default 4 -> 8
    - ADCBB n [ovs]: DMA-free ADC core timing (25.05 ns/conversion measured)
    - ACQCPU trg [rptcnt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
2026-10-28 docs: changelog — record 84ea839 / d17d0fc under Committed (fix the missed edit)
    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
2026-10-28 docs: datasheet check — TRG1SRC 2/3 are Reserved (only TRG2SRC); 2-sum at 20 M/s not possible on one channel
    Answers "could it do 20 Msps integrated over 2 samples?": oversampling starts at
    ACCNUM=4, integration CNT=2 measured at 88 ns per sum (11.4 M/s max), and the
    re-trigger / repeat-timer sources are Reserved as TRG1SRC so the per-trigger
    overhead cannot be skipped. Possible CH0+CH1 interleave route noted in TODO.
    Also records 77d725a in the changelog and COMMITS.md.
    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
2026-11-02 feat(firmware): OA2 gain control — RP i2c scan + pot <0|1> [n] (MCP4531), PIC AMP2 0|1 (pic 0.1.21 / rp 0.1.29, proto 6)
    OA2 (PIC op amp 2) = non-inverting stage on OA1OUT with U11 MCP4531-103 (I2C 0x2E) as feedback
    rheostat against R49 1k: gain 1 + R_AW/1k = x1.07..x11.07, power-on wiper 64 = x6.08. RP: I2C0 init,
    'i2c' scan (0x2E U11, 0x2F U18, 0x60 MCP4728 answer; no OLED), 'pot' read/set with gain print.
    PIC: 'AMP2 0|1' (off at boot). Bench-verified wiper write/read-back. MCP453X datasheet filed
    (pdfs/datasheets, with .md): 10k part -3 dB = 1 MHz -> OA2 is bandwidth-limited by the digipot,
    hardware TODO. Memory 0012 (RX chain + measurement procedure), README command tables, session log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
2026-11-02 docs: session 08 part 4 — OA2 gain-control alternatives; direction = GPIO-switched gain legs, no digipot/VGA
    Owner constraint: BOM cost + simple design with RP2354 + PIC32AK as the core (AD8338 too costly).
    Ranked: GPIO-switched ground legs on OA2 (zero parts, stepped TGC on a timer) > analog switch >
    JFET VCR > software-only TGC; low-R digipots (AD5273/AD8400 1k, 5-6 MHz) and PGAs (MCP6S91) noted.
    Devkit rework + GAIN <mask> command planned. Also: J6.1 (OA1OUT) has no IPEX (RF5/RF13/RF7 do).
    Memory 0012 and TODO updated.
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2026-11-06 docs: session 09 — FE-A op-amp fixes, gain switching, per-stage GBW limit, BGA2817/BGA2869 MMIC LNA proposal (memory 0013)
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2026-11-06 docs: park the BGA2817 MMIC LNA as a board-redesign candidate
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2026-11-07 hardware: add minUS_07112026 (slim board: BGA2817 LNA + 74HC4052 gain mux) + review notes
    Review (memory 0014, TODO_HARDWARE, session 09 log): aligned with the RX recos; must-fix =
    floating 4052 selects, 330 pF LNA input cap, MCLR R17, input clamp to rails.
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2026-11-08 hardware: add minUS_08112026 + review; ×1 gain via PIC UGE bit
    Review (memory 0014): C3/C32 10 nF, C45 DC block, 51 Ω termination, MCLR 0 Ω, AVDD ferrite,
    4052 selects driven. Regression: gain selects took RP GPIO21/22 so PGC1/PGD1 no longer reach
    the RP. Still open: D2 clamp/bleed, Cf, anti-alias, ADC2 routing, test points.
    ×1 gain per stage comes from AMPxCON1.UGE (DS70005592 §32.4.2.1), no 0 Ω Rf needed.
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2026-11-08 hardware: minUS_08112026 2nd iteration + review (all must-fix resolved)
    ICSP restored on RP GPIO21/22, 4052 selects on GPIO25/23, D2 antiparallel
    to GND, PIC32_ADC on AD2AN9 (ADC2) + H6.13, R65/R66 removed. Remaining:
    C86/C87 -> ~100 pF, DNP Cf, optional bleed/pull-downs; firmware needs an
    ADC2 capture path (memory 0014, TODO_HARDWARE, TODO, session 09 log).
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2026-11-08 hardware: minUS_08112026 layout pass + JLC outputs; U3 substitution noted
    Parts moved by the owner, Fabrication Toolkit outputs regenerated with LCSC
    numbers. DRC: 0 shorts/unconnected/parity issues; 25 clearance errors, all
    from the two silkscreen QR codes. Owner removed the gerber_to_order zip and
    board PNGs. U3 MIC4427YMM (C152165) replaces out-of-stock TC4427AEUA713;
    design files and bom.csv still list the TC4427 (memory 0014).
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2026-11-11 hardware: 3D renders of minUS_08112026 + render_3d.py script
    Model paths in the PCB point at a Windows library; render_3d.py remaps them
    to vendored EasyEDA models (hardware/3dmodels/EasyEDA) and stock KiCad
    substitutes, fixes U1/U.FL orientation, and always omits 2xN/IDC headers
    and SMA connectors.
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

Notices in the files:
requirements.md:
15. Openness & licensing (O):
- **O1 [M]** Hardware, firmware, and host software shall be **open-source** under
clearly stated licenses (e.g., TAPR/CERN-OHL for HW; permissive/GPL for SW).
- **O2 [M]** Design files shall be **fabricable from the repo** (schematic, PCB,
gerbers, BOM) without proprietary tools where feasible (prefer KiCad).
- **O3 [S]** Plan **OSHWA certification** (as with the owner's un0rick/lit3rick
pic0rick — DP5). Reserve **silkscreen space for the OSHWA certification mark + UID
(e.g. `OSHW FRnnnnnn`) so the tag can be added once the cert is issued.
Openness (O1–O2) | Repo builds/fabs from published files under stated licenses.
